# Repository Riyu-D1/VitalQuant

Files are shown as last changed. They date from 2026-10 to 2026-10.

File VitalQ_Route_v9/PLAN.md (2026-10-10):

# VitalQ v9 execution plan

## Source and protection

Start from the hand-edited v9 board dated 2026-10-09 10:19. Do not use the newer autosave. The B0_original backup preserves the starting board/project/schematic/local project. v8 is read-only; Python imports from it must use -B/PYTHONDONTWRITEBYTECODE. No parts or net assignments may change. All locked parts, connectors, electrodes, mounting holes, outline, skin-side sensor placement and rule areas remain unchanged. U19, or U18 only if needed, may move with a complete reconnection and logged before/after. Unlocked small passives may move no more than 1 mm, logged individually.

## Rules

Source checked: https://jlcpcb.com/capabilities/pcb-capabilities (2026-10-09).

- Exactly six copper layers, ENIG, 1 oz capability basis. No 8-layer conversion.
- Global and netclass track width/clearance remain 0.1016 mm; never below 0.09 mm.
- Presets: 0.25 mm diameter / 0.15 mm hole for BGA POFV; 0.40 / 0.20 mm ordinary vias.
- Minimum diameter 0.25 mm, drill 0.15 mm, annular ring 0.05 mm, matching the explicitly requested 0.25/0.15 geometry. Larger existing lawful vias need not all be replaced.
- Via hole-to-foreign-copper and drilled hole-to-hole edge separation: 0.20 mm, enforced by project minima and vitalq_v2.kicad_dru. Same-net attached tracks/annuli are necessarily connected to the hole and are not foreign-copper clearance checks. Hole-to-hole applies regardless of net.
- Copper-to-outline/slot clearance remains 0.30 mm.
- Through vias only. Blind, buried and micro vias disabled and prohibited by custom rule.
- All via-in-pad must be explicitly flagged filled/capped and listed for epoxy-filled, copper-capped POFV ordering. JLC advertises this process on 6-layer boards; confirm actual order options and any small-hole surcharge rather than assuming every service is free.
- Never add vias or inner copper in hv_inner areas; never modify rule areas, including J8. A geometrically blocked pad is not authorization to notch a keepout.

## Ordered work

1. Back up, establish rules/presets, save/refill baseline DRC. Also retain inherited-rule comparison.
2. Correct the five named 0.6/0.3 vias and move LED2_K off In1.Cu, preserving existing connections.
3. Local GND repairs; C59/U18 +3V3 stitches; sensor bridge and TMP117_ALERT; J12 MP; evaluate fully reconnected U19 relocation.
4. U7 exact 0.25/0.15 POFV escapes on In2/B, with a local MISO_AD detour only if required.
5. U6/U22 authorized local rip-up window and POFV, restoring all removed-net connections; In3 fallback only with connected power pours.
6. Remaining outer-layer HV-safe long runs.
7. Keepout, via spacing, dangling copper and pad-clearance cleanup without rule relaxation.
8. Final saved/refilled DRC, geometry/protected-placement/connectivity audit, renders and complete report.

## Attempts and acceptance

Review v9 PROGRESS.md and v8 PROGRESS.md/REPORT.md before each attempt. Keep v8 failed approaches in the ledger; the explicit v9 strategies are not permission to repeat exhausted v8 searches. At most three genuinely distinct v9 attempts per net; inherited exhaustion remains visible. No grid-resolution-only retries. Count routing batches with no accepted open reduction, including search-only failures. Two consecutive non-improving routing batches stop routing and send all remaining work to the report. Rule establishment is the baseline, not a routing attempt. Artifact correction counts as a routing batch if copper is changed.

Every batch gets a dated backup first and exactly one outcome line afterward in PROGRESS.md. Candidate projects retain the same PCB/project/rules basename. Never accept stale-fill DRC. Accept only candidates preserving all original connected pad groups and protected geometry, with no new real DRC defects; a capped keepout count must be audited geometrically. Rejected candidates remain archived, not deleted. Track every via, segment change/removal, nudge, attempt and blocked reason in JSON ledgers. Freerouting, if justified, is one named-BLOCKED-net-only run with fixed original copper and a 10-minute timeout; not a fallback that bypasses the mandatory stop.

DRC command: /Applications/KiCad/KiCad.app/Contents/MacOS/kicad-cli pcb drc --refill-zones --save-board --all-track-errors --schematic-parity --format json -o <report> vitalq_v2.kicad_pcb.

Reported real violations exclude only library and silk/text presentation findings; parity is separate. KiCad's per-code cap means native totals are lower bounds and cannot replace the uncapped geometry audit. No manufacturing-release claim while opens or real violations remain.

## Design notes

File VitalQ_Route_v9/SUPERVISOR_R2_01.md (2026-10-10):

# Supervisor instructions R2 #01 (answers to your 5 questions + next batches)

Streak/acceptance policy for R2 (replaces the generic rule):
- R2-1 (restack) is structural and does NOT count toward the stop streak. Streak = 0 now.
- A batch is ACCEPTED if, after refilled DRC, unconnected does not rise AND real violations do not rise vs the batch start; it counts as "improving" if unconnected falls OR real violations fall. Stop only after two consecutive non-improving batches, then print "R2 STOPPED" and wait (as before).
- Per-net attempt counters for C59.1, U18.8, ADS1292_PWDN, IR_GATE, AD5940_RESET are reset, because the geometry changes below (part moves) make them new problems.

Answers:
1. Streak: reset (see above).
2. YES: local rip-up and re-route of +3V3_ANA, TX_5V and MISO_FL (and any other foreign F.Cu/B.Cu segment hit by the moved U18 pads/EP) inside x 23.5–29.5, y 39.5–49.0 is authorised. Log every removed segment uuid. Keep the U18 dx = -0.31 mm nudge (needed for U22 C1/D1 via-in-pad).
3. YES: local rip-up of the blocking F.Cu/B.Cu segments around U19, C59 and U18.8 is authorised, including inside the HV area ON OUTER LAYERS ONLY (hv_ownlayer only forbids pours). Re-routes inside any hv_inner area must stay on F.Cu/B.Cu; In2/In3 re-routes only outside hv_inner. Log every removed segment.
4. NO: do not accept a via touching the hv_inner edge. Use the part moves below instead.
5. YES: run the U19.16/D30.2 GND island fix by itself as batch R2-3 right now (43 -> 42). Accept it.

Placement moves (supervisor-instructed; verified on a copy: courtyard-legal, inside board outline, and they move ALL signal pads out of every hv_inner area):
- U19: move dy = +1.00 mm, dx = 0 (17.0877,43.4355 -> 17.0877,44.4355), rotation unchanged. With this move 0 U19 net pads remain inside hv_inner. Re-attach all U19 pin tracks (shift/re-route stubs), then drop the vias for ADS1292_PWDN, IR_GATE, AD5940_RESET (and any other U19 inner-layer escapes) OUTSIDE hv_inner, i.e. below y 43.4 band edge where the pin now lies. Alternative legal positions if needed: (dx,dy) = (+0.25,+1.0), (+0.5,+1.0), (+0.75,+1.0), (+1.0,+1.0).
- C59: move (dx,dy) = (+0.25, -1.00) (15.6477,40.5098 -> 15.8977,39.5098), rotation unchanged. This puts C59.1 out of hv_inner and is courtyard-legal (1.03 mm; authorised exception to the 1 mm passive limit). Re-attach C59.2 and give C59.1 a 0.4/0.2 via to the +3V3 plane (now In4) outside hv_inner. Alternatives: (+0.5,-1.0), (+0.75,-1.0).
- Log both moves in change_ledger.json and REPORT.md.

Batch order now:
- R2-3: GND island U19.16/D30.2 alone (accept at 42).
- R2-4: U19 move + C59 move + re-attachment + ADS1292_PWDN / IR_GATE / AD5940_RESET / C59.1 escapes (treat as one batch; acceptance at batch end).
- R2-5: U18 nudge (-0.31) + authorised rip-up/re-route around U18 + U18.7/U18.8 +3V3 vias (pin8 now outside hv? check; if still inside, F.Cu stub out of hv_inner to its own via).
- Then continue with PROMPT_R2 R2-3.. steps (via-in-pad fan-out U22/U6/U7, U6/U22 bottom-ring rip-up, remaining routing), renumbered sequentially.
After every batch print the 3-line summary. I render each batch and will send more exact instructions.

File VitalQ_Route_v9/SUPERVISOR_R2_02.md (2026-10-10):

# Supervisor instructions R2 #02 (priorities + expanded authority from the user)

## Expanded authority (user, 17:45) — log every use in change_ledger.json + REPORT.md
- Board size: chest wearable. Stay at 50 x 75 mm if at all possible. Grow ONLY after placement moves and via-in-pad have been tried, and then only a few mm (hard cap 55 x 80 mm); no other shape change without a stated reason.
- You may move/rotate ANY unlocked part, and (within the size cap above) reshape the board outline, and change stackup/via tech (8 layers or HDI only if truly needed; note cost) — netlist/function identical, no parts added/removed.
- Locked parts (skin-side sensor cluster U6/U22/U11/U20/U16, HV corridor parts, connectors J*) MAY now be moved if they are the blocker, but: skin sensors stay on the skin side, stay together as a cluster and still face/contact the skin; HV keeps its isolation clearances (rule areas move WITH their HV parts, same shape and clearance, never shrink); connectors stay reachable at the board edge. Prefer moving unlocked parts first.
- Do not loosen any JLC rule. No commit/push. Delete no files.

## Priority order (do not sink more than one more attempt into U19 now)
1. U19: ONE more attempt with a minimal-disturbance method: "drag with tracks" instead of rip-up. Move U19 (dy +1.00, or rotate 180 deg + dy +1.00 if that puts pins 3/4/7 facing open space south of y 44), move every track endpoint that sits on a moved pad centre by the same transform, keep the rest of each track, then only fix the resulting local clearance hits. Place the escape vias for pins 3 (ADS1292_PWDN), 4 (AD5940_RESET), 7 (IR_GATE) south of the hv_inner band (y > 43.4 + 0.2 + via radius). If it still fails, park U19 (mark DEFERRED, not BLOCKED) and move on.
2. U7 via-in-pad batch (13 opens, biggest win, sites were clear in the survey): 0.25/0.15 POFV at ball centres B3 BIOZ_FP, B4 AIN4_LPF0, B5 BIOZ_SP, B6 DE0, B7 VZERO0, C7 VBIAS0, D2 BIOZ_FN, D7 VREF_2V5, E7 SPI_MOSI, F2/F3 +3V3_ANA, F5 AD5940_GPIO0, F7 CS_AD5940; escape on In3 ("Signal Layer 4", now empty) first, In2 second, B third; reroute the single B.Cu MISO_AD track that blocks the F row. Split into two batches if needed (B/C/D rows, then E/F rows).
3. U22 via-in-pad + U18 nudge (R2-5 from #01) — LED1_K D1, LED2_K C1, LED3_K B1, MAX86178_INT B2 at x 26.9/26.5; escape on In3.
4. U6 via-in-pad + bottom ring rip-up (PROMPT_R2 R2-3/R2-4), escapes on In3/In2.
5. Leftovers (+3V3 stitches, TMP117_ALERT, J12 MP, AFE_N_PAD, U18.7/8, C59.1, U19 deferred) — if a pin is boxed in, move the part (authority above) instead of retrying the same geometry.
6. Cleanup to DRC clean (items_not_allowed, hole_clearance 0.2, dangling, SOT-23 clearances) — 0 real violations except the 29 accepted parity items and library/silk/text presentation warnings.
7. Fab outputs into ./fab/: JLC Gerbers (all 6 copper + masks, paste, silk, Edge.Cuts) + Excellon drill (PTH/NPTH) zipped as fab/vitalq_v2_gerbers.zip; BOM (fab/vitalq_v2_BOM.csv, JLC columns Comment,Designator,Footprint,LCSC) and CPL (fab/vitalq_v2_CPL.csv, Designator,Mid X,Mid Y,Layer,Rotation) via kicad-cli; fab/FAB_NOTES.md: 6-layer S/G/S/S/P/S, ENIG, 1.6 mm, via-in-pad POFV (epoxy filled + capped) for the 0.25/0.15 vias, min via 0.15 hole, track/space 0.09/0.1016. Verify: re-open gerbers with kicad-cli gerber/drill check or a parse, count layers/files, CPL refs == BOM refs == board footprints.

Keep the 3-line summary after every batch. I am watching every 5-10 minutes and will send exact geometry when you report a block.

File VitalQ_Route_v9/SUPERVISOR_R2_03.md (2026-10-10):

# Supervisor instructions R2 #03 — KEEP the R2-6 candidate and repair it (do not discard)

R2-6 candidate (candidates/R2-6/vitalq_v2.kicad_pcb) is a real improvement: unconnected 42 -> 32, real 252 -> 245, hole_clearance 40 -> 26. Its 7 "new faults" are 6 track_dangling + 1 via_dangling WARNINGS plus 2 nets it broke (SWEAT_WE, MISO_AD). Make it the base of batch R2-7 (copy it over the working board after a dated backup) and repair on top of it. Acceptance for R2-7: unconnected < 32 + 0 and real <= 245 and no new dangling items.

I rendered the candidate (F/In2/In3/B around U7) and queried its copper. Exact fixes:

## 1. Dangling In3 stubs (delete the dangling segment only; the nets are connected elsewhere)
- CS_AD5940, Signal Layer 4: stub ending near (36.536,10.181) (vertical (36.586,9.55)->(36.586,10.28) leftover).
- VBIAS0, Signal Layer 4: (36.486,11.431), 0.65 mm stub west of C7 via (36.586,11.481).
- BIOZ_FP, Signal Layer 4: (38.136,11.981), 0.7 mm stub south of B3 via (38.186,11.881).
- BIOZ_SP, Signal Layer 4: (37.436,11.981), 0.7 mm stub south of B5 via (37.386,11.881).
- BIOZ_FN, Signal Layer 4: (38.686,11.031), the dangling part of the T east of D2 via (38.586,11.081) (keep the part that leads to the long vertical at x~38.99 if that is the real route).
- uuids from your decision.json: 35a19dc6, 3854008f, 47792255, adf22370, eec6d8c7 (check each is one of the above before deleting). Pre-existing GND dangling (28.936,37.201) / via (6.829,62.871) / AFE4900_RESETZ zero-length (10.75,61.05) are old — leave them for cleanup.

## 2. SWEAT_WE (U7 C5 @ 37.386,11.481) — currently boxed in by via-in-pads
Neighbouring via-in-pads: D5 GND (37.386,11.081), C4 GND (37.786,11.481), B5 BIOZ_SP (37.386,11.881); the only free neighbour pocket C6/D6 (36.986,11.481 / 11.081) is closed by C7 VBIAS0, D7 VREF_2V5, E6 GND, B6 DE0 vias. At 0.4 pitch no track can pass between two via-in-pads (JLC 0.2 hole-to-track), so a via must go.
- Delete the GND via-in-pad at D5 (37.386,11.081) (GND is redundant here: E6 and C4 GND vias stay). Tie D5 pad to E5 pad (37.386,10.681, GND) with a straight 0.1016 F.Cu track; make sure E5 reaches E6 (36.986,10.681) or E4/E3 GND on F (add the 0.4 mm pad-to-pad F track E5->E6 if not already there).
- Inner-layer channel now open (all of these balls have NO via): D5 (37.386,11.081) -> D4 (37.786,11.081) -> D3 (38.186,11.081) -> C3 (38.186,11.481) -> C2 (38.586,11.481) -> B2 (38.586,11.881) -> A2 (38.586,12.281) -> south out of the array; and the north branch D4 -> E4 (37.786,10.681) -> F4 (37.786,10.281) -> G4 (37.786,9.881) -> north out. Track centres on ball centres are 0.40 from every neighbouring via (legal: needs >= 0.32 for a 0.09-0.1016 track).
- Route SWEAT_WE from the C5 via on In2 (or In3) through one of those channels to the rest of the net. The net continues on B.Cu from via (36.95,14.55) down to (36.95,16.0) -> (37.15,16.35) -> (38.3,17.5) -> (38.65,17.75..18.9) ...; you may join that B track anywhere (e.g. drop a new 0.4/0.2 via on the In2/In3 path and land on the B track near (37.15,16.35)-(38.3,17.5)), and then delete the orphaned old In2 piece (36.85,12.70)->(36.8,14.4)->via(36.95,14.55) and that via if they become dangling.

## 3. MISO_AD (U7 E8 @ 36.186,10.681 -> R91.1 @ 44.313,11.855)
- The old B.Cu run along y~10.24 was ripped because it sat on the F-row via-in-pads (y 10.281). Left: F stub E8 -> via (34.465,10.447) with B stub to (34.607,10.305); and R91 side F track -> via (43.224,11.147) with B stub to (43.082,11.006).
- Via-free inner channels through U7: row G (y = 9.881, all G balls have no via) and column 8 (x = 36.186, no vias). On B there are now only via barrels under U7 plus the CS_AD5940 / SPI_MOSI escape diagonals west of U7 (to (36.586,10.281) and (36.586,10.681)).
- Preferred: B.Cu from via (34.465,10.447) north/around the CS_AD5940 diagonal to y ~9.3, east along y ~9.3 (north of row G, clear of the G-row pads which are F-only), then down the east side to via (43.224,11.147). If B is blocked west of U7, use In2 along row G (y 9.881) between the F-row vias (0.40 clearance) — but first check In2's diagonal near (35.0,10.95)->(37.64,8.5); use In3 if that one is in the way. Reuse the two existing MISO_AD vias; delete the two 0.2 mm B stubs if not used.

## After R2-7
Continue SUPERVISOR_R2_02 priorities: U22 via-in-pad + U18 nudge next, then U6. Print the 3-line summary after each batch.

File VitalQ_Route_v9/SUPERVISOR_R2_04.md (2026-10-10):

# Supervisor instructions R2 #04 — U6 (AFE4900, B side, 0.4 mm WLP) escape plan
(from renders of candidates/R2-7 + copper query; use after the U22 batch)

## Grid (B side balls; x by column, y by row)
cols: 1=26.5, 2=26.1, 3=25.7, 4=25.3, 5=24.9 ; rows: A=49.8, B=50.2, C=50.6, D=51.0, E=51.4, F=51.8
Opens on U6: A1 AFE_INM, A2 PD_INP, A3 PD_INM, B2 PD2_INP, B3 PD2_INM, C4 +3V3_ANA, D2 AFE_BG, D4 TX1, E2 MISO_AFE, E3 CS_AFE4900, E4 TX3, E5 TX2, F2 SPI_MOSI, F3 SPI_SCK.
Existing GND via-in-pads (keep): B4 (25.3,50.2), D1 (26.5,51.0), D5 (24.9,51.0).

## Layer situation under U6 (rendered)
- In3 (Signal Layer 4): EMPTY under and around U6/U22. Use it first.
- F.Cu above U6 (x 24.4–27.0, y 49.4–51.9): EMPTY except the GND via tops. Usable as an escape layer (U6 is on B). TX_5V F diagonal (27.13,49.27)->(29.03,51.17) is the first obstacle east.
- In2: two foreign tracks run THROUGH the array and must be ripped inside x 24.0–27.0, y 49.0–52.2 (authorised, log uuids) and re-routed afterwards outside the array:
  - ESP_TX: (24.84,49.93)->(24.84,50.25)->(25.26,50.70)->(25.26,51.15)->(24.84,51.45) (sits on C4/D4/E4 sites).
  - AFE_INP: (26.97,49.71 via)->(26.95,50.0)->(26.95,51.2)->(26.36,51.4)->(26.36,54.6) (sits on the E1/F1 east channel and between col1/col2). Re-route AFE_INP from its B1 pad stub/via (26.97,49.71) on In2 EAST of x 27.3 or on F.
- B.Cu: ring of TX4 / TX_5V / +1V8 / +3V3_ANA / AFE_CLK / ADC_RDY / RESETZ / AFE_INP hugging the array — leave it; all new escapes go through via-in-pad to F/In2/In3.

## Via-in-pad set (0.25/0.15 POFV at ball centre)
A1, A2, A3, B2, B3, C4, D2, D4, E2, E3, E4, E5, F2, F3 (+ existing B4, D1, D5).
Free (no-via) cells that form the channels: A4, A5, B1, B5, C1, C2, C3, C5, D3, E1, F1, F4, F5.
Rule reminder: a track on a ball-centre line is 0.40 from the neighbouring via centres (legal, >= 0.32 needed); a track can NOT pass between two adjacent vias or diagonally past one (0.28).

## Escape topology (forced by the grid)
- Row A (A1, A2, A3): boundary — escape NORTH (y < 49.6) on any layer.
- E5, F2, F3: boundary — escape west (E5) / south (F2, F3).
- E4 TX3: E4 -> F4 (25.3,51.8) -> south.
- C4 +3V3_ANA: C4 -> C5 (24.9,50.6) -> west.
- E2 MISO_AFE: E2 -> E1 (26.5,51.4) -> east.
- B2 PD2_INP: B2 -> B1 (26.5,50.2) -> east.
- B3 PD2_INM, D2 AFE_BG, D4 TX1, E3 CS_AFE4900 all MUST use the C2 -> C1 -> east exit (B3 via C3; D4 and E3 via D3 -> C3; D2 directly via C2). That is 4 nets through one cell sequence, so they need 4 different layers: assign D2 AFE_BG = F.Cu (target C15.1 @ 28.776,50.042 is on F; cross the TX_5V F diagonal by dropping to In3 for 0.5 mm or go around its north end at (27.13,49.27)), B3 PD2_INM = In3, D4 TX1 = In2 (after the ESP_TX/AFE_INP rip), E3 CS_AFE4900 = In4 (Power Layer 5: a short local track is allowed; the +3V3 pour refills around it and must stay connected — check) OR move CS_AFE4900 onto F and AFE_BG onto In4. If you find a 3-layer solution, better.
- After exiting east (x >= 26.9), PD2_INP / PD2_INM / TX1 must loop to U16 (B side, locked, 13.4,56.0; pads PD_INP 10.4,57.25 / PD_INM 11.6,57.25 / PD2_INP 12.8,57.25 / TX1 16.4,57.25 / TX3 15.2,54.75 / PD2_INM 12.8,54.75 / TX2 10.4,54.75): go south on In3 east of the array (x ~27.0–27.3, In3 is empty there), then west along y ~52.5–53.5 on In3 under U6's south side, then to U16 with vias next to its pads (outside any hv_inner area). PD_INP / PD_INM (A2/A3) go north 0.3–0.8 mm, then west on In3 along y ~49.0/49.4, then south-west to U16.
- A1 AFE_INM joins its existing F.Cu track (8.39 mm piece) — via A1 to F, then F.
- MISO_AFE (E2) target R90.1 (44.897,49.062, F) — east on In3/In2, via near R90.
- SPI_MOSI / SPI_SCK (F2/F3): south via F row, then to the SPI bus (SPI_SCK must also reach U22 A2 @26.5,46.95).

Do this as one or two batches (row-A/E5/F-row/E4/C4/E2/B2 first; then the 4-layer C-channel group). Print the 3-line summary after each.

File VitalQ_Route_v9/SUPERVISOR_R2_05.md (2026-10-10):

# Supervisor instructions R2 #05 — decision on the J8 no-via area over U6

J8 = Tag-Connect TC2030-IDC-NL on F at (26.45,53.2), locked. Its footprint no-via/no-fill F rule area covers x 25.18–27.72, y 50.06–51.34, i.e. U6 balls B1–B4, C1–C4, D1–D4 (and E-row annuli touch it). v8 already granted two POFV exceptions there (D1/B4 GND) using per-via notches (see ../VitalQ_Route_v8 j8_pofv_policy.json, scripts/j8_pofv.py).

DECISION (user granted structural authority): extend the SAME v8 mechanism to every U6 via-in-pad you need under J8.
- Allowed: 0.25/0.15 via-in-pad exactly at U6 ball centres, POFV (epoxy-filled + copper-capped, planar), each with its own notch in the J8 F no-via area of exactly the via annulus + 0.002 mm, recorded in j8_pofv_policy / j8_permitted_vias (new R2 file is fine). Rationale: the area exists so the Tag-Connect head sits on a flat surface; a POFV cap is planar and soldermask-covered.
- Not allowed: any non-POFV via, any between-ball via, any track/via change elsewhere in the J8 area, any change to hv_* rule areas.
- Flag all of them in REPORT.md and fab/FAB_NOTES.md as "POFV mandatory (planar, under Tag-Connect J8 landing)".
- Fallback only if this proves impossible: rotate J8 180 deg and shift dx +0.50 mm (-> 26.95,53.2): verified courtyard-legal, its keepout then lands at x 25.68–28.22, y 55.06–56.34 covering 0 U6 balls and 0 existing vias; but it needs re-attachment of all 6 J8 nets and relocation of the GND via (25.798,52.987), +3V3 via (24.589,54.532) and ESP_EN via (29.6,53.283) which would collide with the moved pads/NPTH holes. Use only if the notch approach fails.

So: proceed with the full U6 plan of SUPERVISOR_R2_04 including the J8-covered balls (B2, B3, C4, D2, D4, E2, E3, E4) using notched POFV exceptions.

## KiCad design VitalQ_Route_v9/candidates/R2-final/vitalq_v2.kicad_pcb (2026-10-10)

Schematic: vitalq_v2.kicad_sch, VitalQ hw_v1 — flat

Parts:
C1, C47: 4.7u; C_0603_1608Metric
C2, C9, C20: 4.7u; C_0402_1005Metric
C3, C4, C6, C11, C14, C16, C19, C26, C32, C33, C42, C43, C64, C66, C80, C82, C83, C84: 1u; C_0402_1005Metric
C7, C45: 22u; C_0603_1608Metric
C8, C13, C15, C18, C24, C25, C27, C28, C29, C36, C37, C38, C39, C40, C41, C50, C51, C56, C57, C58, C59, C60, C61, C62, C63, C76, C77, C78, C79, C81: 100n; C_0402_1005Metric
C10: 1u; C_0603_1608Metric
C21, C22, C23, C55, C68, C69, C70: 470n; C_0402_1005Metric
C30: 10u; C_0402_1005Metric
C34: 47n; C_0402_1005Metric
C35: 4.7n; C_0402_1005Metric
C44: 10u; C_0603_1608Metric
C46: 2.2u; C_0402_1005Metric
C48, C49, C52, C53: 2.2n; C_0402_1005Metric
C54, C67: 15n; C_0402_1005Metric
C65: 1.5n; C_0402_1005Metric
C85: 47u; C_0603_1608Metric
C86, C88, C90, C91: 100n; C_0402_1005Metric; LCSC C1525
C87: 10u; C_0402_1005Metric; LCSC C15525
C89: 10u; C_0603_1608Metric; LCSC C19702
D1, D2, D3, D4, D5, D6, D7, D8, D9, D21, D22, D23, D24, D26, D27, D28, D29, D30: TPD1E10B06; TPD1E10B06_DPY
D10: NF2W757G-F1; NF2W757G
D11: SFH4053; LED_0402_1005Metric
D12: SFH 4735 730nm; LED_0402_1005Metric
D25: KT-0603G; LED_0603_1608Metric
FID1, FID2, FID3, FID4, FID5, FID6: FID; Fiducial_1mm
H1, H2: M2; MountingHole_2.2mm_M2
J1: USB-C; USB_C_Receptacle_HRO_TYPE-C-31-M-12
J2: LiPo pads; Pads_LiPo
J3: FSR pads; Pads_FSR
J5: ECG pads; Pads_ECG
J6: EDA pads; Pads_EDA
J7: Chest bioZ; Pads_BIOZ
J8: TC2030; Tag-Connect_TC2030-IDC-NL_2x03_P1.27mm_Vertical
J9: I2C tail pads; Pads_1x04
J10: Optical tail pads; Pads_1x06
J11: Sweat site; Pads_1x03
J12: FH12-14S; Hirose_FH12-14S-0.5SH_1x14-1MP_P0.50mm_Horizontal; not fitted
J13: MX ECG pads; Pads_1x02; not fitted
L1: 0.47u; L_DFE201612E
L2: 1.0u; L_DFE201612E
Q1, Q2, Q4: CSD13380F3T; Texas_PicoStar_DFN-3_0.69x0.60mm
Q3: BC847BS,115; SOT-363_SC-70-6
R1, R2: 5.1k; R_0402_1005Metric
R3: 1.5k; R_0402_1005Metric
R5, R6, R7, R8, R9, R11, R14, R49, R52, R53, R60, R65, R67, R68, R69, R70, R71, R74, R98, R100, R101, R112, R113, R115, R116, R117: 10k; R_0402_1005Metric
R10, R13, R39, R40, R41, R42, R62, R72, R73, R84, R85, R86, R87, R88: 1k; R_0402_1005Metric
R12: 10; R_0402_1005Metric
R15, R16, R17: 1M; R_0402_1005Metric
R18, R51: 200k; R_0402_1005Metric
R19, R20, R21, R22: 4.7k; R_0402_1005Metric
R23: 560k; R_0402_1005Metric
R24, R25, R44, R46, R48, R50, R59, R99, R110: 100k; R_0402_1005Metric
R26, R27, R28, R29: 10M; R_0402_1005Metric
R30, R31: 40.2k; R_0402_1005Metric
R32, R33, R34, R35, R36, R76, R77, R78, R79, R80, R81, R82, R83: 51k; R_2512_6332Metric
R43, R45: 5.11M; R_0402_1005Metric
R47, R109: 100; R_0402_1005Metric
R61: 10k; R_0402_1005Metric; not fitted
R63: 22.1k; R_0402_1005Metric
R64: 47.5k; R_0402_1005Metric
R66: 301k; R_0402_1005Metric
R75: 27.0k; R_0402_1005Metric
R89, R90, R91, R92, R95, R96, R97, R102, R103, R106, R114: 0; R_0402_1005Metric
R93, R94: 0; R_0603_1608Metric
R104, R105: 0; R_0402_1005Metric; not fitted
R107, R108: 100k; R_0402_1005Metric; not fitted
R118, R119, R120, R121, R122: 0; R_2512_6332Metric
SW1, SW2: TS-1088; SW_SPST_TS-1088-xR020
TP1: VBUS; TestPoint_Pad_D1.0mm
TP2: VBAT; TestPoint_Pad_D1.0mm
TP3: +3V3; TestPoint_Pad_D1.0mm
TP4: +1V8; TestPoint_Pad_D1.0mm
TP5: TX_5V; TestPoint_Pad_D1.0mm
TP6: VDD_CP2102; TestPoint_Pad_D1.0mm
TP7, TP8: GND; TestPoint_Pad_D1.0mm
TP9: ESP_EN; TestPoint_Pad_D1.0mm
TP10: ESP_IO0; TestPoint_Pad_D1.0mm
TP11: ESP_TX; TestPoint_Pad_D1.0mm
TP12: ESP_RX; TestPoint_Pad_D1.0mm
TP13: I2C_SDA; TestPoint_Pad_D1.0mm
TP14: I2C_SCL; TestPoint_Pad_D1.0mm
TP15: I2C_SDA_1V8; TestPoint_Pad_D1.0mm
TP16: I2C_SCL_1V8; TestPoint_Pad_D1.0mm
TP17: SPI_SCK; TestPoint_Pad_D1.0mm
TP18: SPI_MOSI; TestPoint_Pad_D1.0mm
TP19: SPI_MISO; TestPoint_Pad_D1.0mm
TP20: CS_ADS1292; TestPoint_Pad_D1.0mm
TP21: CS_AFE4900; TestPoint_Pad_D1.0mm
TP22: CS_AD5940; TestPoint_Pad_D1.0mm
TP23: CS_FLASH; TestPoint_Pad_D1.0mm
TP24: ADS1292_DRDY; TestPoint_Pad_D1.0mm
TP25: AFE4900_ADC_RDY; TestPoint_Pad_D1.0mm
TP26: EXP_INT; TestPoint_Pad_D1.0mm
TP27: CHG_STAT; TestPoint_Pad_D1.0mm
TP28: RTC_INT; TestPoint_Pad_D1.0mm
U1: ESP32-S3-MINI-1-N4R2; ESP32_S3_MINI_1
U2: BQ25170DSGR; Texas_DSG0008A_WSON-8-1EP_2x2mm_P0.5mm_EP0.9x1.6mm
U3: TPS63802DLAR; WSON-10-1EP_2x3mm_P0.5mm_EP0.84x2.4mm
U4: TPS7A2018PDBVR; SOT-23-5
U5: CP2102N-A02-GQFN28R; QFN-28-1EP_5x5mm_P0.5mm_EP3.35x3.35mm
U6: AFE4900YZR; BGA30N40P5X6_260X210X50
U7: AD5940BCBZ-RL7; BGA56C40P8X7_416X356X55
U8: ADS1292RIRSMT; QFN40P400X400X100-33N-D
U9: PCA9306DCUR; VSSOP-8_2.3x2mm_P0.5mm
U10: AS7341-DLGM; AS7341DLGT
U11, U20: TMP117AIDRVR; TMP117_DRV_NOPASTE
U12: MLX90632SLD-DCB-100-SP; MLX90632SLDDCB100SP
U13: BME280; Bosch_LGA-8_2.5x2.5mm_P0.65mm_ClockwisePinNumbering
U14: LSM6DSV80XTR; QFN_LSM6DSV80XTR_STM
U15: TPS61240YFFR; TPS61240_YFF
U16: SFH 7072; SFH7072
U17: MAX17048G+T10; TDFN-8-1EP_2x2mm_P0.5mm_EP0.8x1.2mm
U18: W25Q512JVEIQ; W25Q512_WSON8
U19: TCA6408ARSVR; TCA6408A_RSV
U21: USBLC6-2SC6; SOT-23-6
U22: MAX86141ENP+; MAX86141_WLP20; LCSC C5328762
U23: SHT45-AD1B; SHT45_DFN4
U24: RV-3028-C7; RV3028C7
U25: IM69D130
U26: SN74AXC2T245RSWR; Texas_RSW0010A_UQFN-10_1.4x1.8mm_P0.4mm; LCSC C1882550

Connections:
+1V8: C36.1, C86.1, C87.1, C88.1, C90.1, R21.1, R22.1, R66.1, R97.2, TP4.1, U9.2 (VREF1), U10.1 (VDD), U22.C2 (VDD_DIG), U22.D2 (VDD_ANA), U26.7 (VCCA), U26.10 (DIR1)
+1V8_LDO: C6.1, R97.1, U4.5 (OUT)
+3V3: C4.1, C37.1, C38.1, C39.1, C40.1, C41.1, C45.1, C59.1, C60.1, C61.1, C76.1, C77.1, C78.1, C81.1, C84.1, C91.1, D10.1 (A), J3.1, J8.1, J9.1, J12.1, R5.1, R6.1, R7.1, R18.1, R19.1, R20.1, R23.1, R47.1, R49.1, R52.1, R53.1, R60.1, R65.1, R74.1, R94.1, R95.1, R98.1, R99.1, R109.1, R112.1, R113.1, R117.1, TP3.1, U3.6 (VOUT), U4.1 (IN), U4.3 (EN), U11.5 (V+), U12.2 (VDD), U13.2 (CSB), U13.6 (VDDIO), U13.8 (VDD), U14.5, U14.8, U14.12, U18.3 (~WP/IO_{2}), U18.7 (~HOLD/~RESET/IO_{3}), U18.8 (VCC), U19.14 (V_{CCP}), U19.15 (V_{CCI}), U20.4 (ADD0), U20.5 (V+), U23.3 (VDD), U24.7 (VDD), U25.2 (VDD), U26.6 (VCCB)
+3V3_ANA: C11.1, C13.1, C16.1, C18.1, C28.1, C29.1, C43.1, C79.1, C80.1, R12.1, R15.1, R26.1, R28.1, R95.2, R116.1, U6.A4 (I2C_SPI_SEL), U6.C1 (RX_SUP), U6.C4 (IO_SUP), U7.A4 (AVDD_1), U7.F2 (AVDD_2), U7.F3 (DVDD), U8.12 (AVDD), U8.14 (CLKSEL), U8.23 (DVDD)
+3V3_ESP: C7.1, C8.1, R94.2, U1.3 (3V3)
AD5940_GPIO0: U1.18 (IO14), U7.F5 (GPIO0)
AD5940_RESET: R11.1, U7.F1 (~RESET), U19.4 (P2)
ADS1292_DRDY: R99.2, TP24.1, U1.6 (IO2), U8.22 (~DRDY)
ADS1292_PWDN: R14.1, U8.15 (~PWDN/~RESET), U19.3 (P1)
ADS_GPIO1: R100.1, U8.26 (GPIO1/RCLK1)
ADS_GPIO2: R101.1, U8.25 (GPIO2/RCLK2)
AFE4900_ADC_RDY: TP25.1, U1.25 (IO21), U6.F4 (ADC_RDY)
AFE4900_RESETZ: R9.1, U6.E1 (RESETZ), U19.2 (P0)
AFE_BG: C15.1, U6.D2 (BG)
AFE_CLK: R10.1, U6.F1 (CLK)
AFE_INM: C57.2, R45.2, U6.A1 (INM_ECG)
AFE_INP: C56.2, R43.2, U6.B1 (INP_ECG)
AFE_N_AC: D5.1, R36.2, R46.1
AFE_N_PAD: J5.5, R36.1
AFE_N_SER: C57.1, R46.2
AFE_P_AC: D4.1, R35.2, R44.1
AFE_P_PAD: J5.4, R35.1
AFE_P_SER: C56.1, R44.2
AIN4_LPF0: C26.1, U7.B4 (AIN4/LPF0)
AVDD_REG: C42.1, U7.D8 (AVDD_REG)
BIOZ_FN: C68.2, U7.D2 (AIN0)
BIOZ_FN_PAD: J7.2, R81.1
BIOZ_FP: R84.2, U7.B3 (AIN1)
BIOZ_FP_PAD: J7.1, R80.1
BIOZ_SN: C70.2, U7.A3 (AIN2)
BIOZ_SN_PAD: J7.4, R83.1
BIOZ_SP: C69.2, U7.B5 (AIN3/BUF_VREF1V8)
BIOZ_SP_PAD: J7.3, R82.1
CE0: R39.2, U7.A7 (CE0)
CE_ISO: C54.2, D6.1, R39.1
CE_SURGE: C54.1, R76.2
CHG_DIS: Q2.1 (G), R59.1, U19.10 (P7)
CHG_ISET: R3.1, U2.2 (ISET)
CHG_PG: R60.2, U1.11 (IO7), U2.6 (~PG)
CHG_STAT: R49.2, TP27.1, U2.5 (STAT), U19.8 (P5)
CHG_VSET: R75.1, U2.7 (VSET)
CP_DTR: Q3.4 (E2), R70.1, U5.28 (~DTR)
CP_RST: R62.2, U5.9 (~RST)
CP_RTS: Q3.1 (E1), R71.1, U5.24 (~RTS)
CP_RX: R72.2, U5.25 (RXD)
CP_TX: R73.1, U5.26 (TXD)
CP_VBUS: R63.2, R64.1, U5.8 (VBUS)
CS_AD5940: R7.2, TP22.1, U1.19 (IO15), U7.F7 (~CS)
CS_ADS1292: R98.2, TP20.1, U1.14 (IO10), U8.18 (~CS)
CS_AFE4900: R116.2, TP21.1, U1.22 (IO18), U6.E3 (SEN)
CS_FLASH: R52.2, TP23.1, U1.20 (IO16), U18.1 (~CS)
CS_MAX86178: R117.2, U1.34 (IO38), U22.A5 (CSB), U26.2 (OE)
DE0: R42.2, U7.B6 (DE0)
DE_SURGE: D9.1, R42.1, R79.2
DVDD_REG: C23.1, U7.G3 (DVDD_REG_1V8)
ECG1_PAD: J5.1, R32.1
ECG2_PAD: J5.2, R33.1
ECG_N: C51.1, C53.1, D2.1, R31.2, R33.2, U8.5 (IN2N)
ECG_P: C50.1, C52.1, D1.1, R30.2, R32.2, U8.6 (IN2P)
EDA_CE_PAD: J6.1, R76.1
EDA_DE_PAD: J6.4, R79.1
EDA_RE_PAD: J6.2, R78.1
EDA_SE_PAD: J6.3, R77.1
ESP_EN: C64.1, J8.5, Q3.6 (C1), R5.2, SW1.1, TP9.1, U1.45 (EN), U19.1 (~RESET)
ESP_IO0: J8.6, Q3.3 (C2), R6.2, SW2.1, TP10.1, U1.4 (IO0)
ESP_RX: J8.4, R73.2, TP12.1, U1.40 (RXD0)
ESP_TX: J8.3, R72.1, TP11.1, U1.39 (TXD0)
EXP_INT: R53.2, TP26.1, U1.7 (IO3), U19.11 (~INT)
FB_3V3: R23.2, R24.1, U3.4 (FB)
FN_ISO: C68.1, D22.1, R85.2
FN_SURGE: R81.2, R85.1
FP_ISO: C67.2, D21.1, R84.1
FP_SURGE: C67.1, R80.2
FSR_ADC: J3.2, R8.1, U1.5 (IO1)
GAUGE_ALRT: R74.2, U1.10 (IO6), U17.5 (ALRT)
GND: C1.2, C2.2, C3.2, C4.2, C6.2, C7.2, C8.2, C9.2, C10.2, C11.2, C13.2, C14.2, C15.2, C16.2, C18.2, C19.2, C20.2, C21.2, C22.2, C23.2, C24.2, C25.2, C26.2, C28.2, C29.2, C30.2, C32.2, C33.2, C36.2, C37.2, C38.2, C39.2, C40.2, C41.2, C42.2, C43.2, C44.2, C45.2, C46.2, C47.2, C48.2, C49.2, C52.2, C53.2, C58.2, C59.2, C60.2, C61.2, C62.2, C63.2, C64.2, C66.2, C76.2, C77.2, C78.2, C79.2, C80.2, C81.2, C82.2, C83.2, C84.2, C85.2, C86.2, C87.2, C88.2, C89.2, C90.2, C91.2, D1.2, D2.2, D3.2, D4.2, D5.2, D6.2, D7.2, D8.2, D9.2, D21.2, D22.2, D23.2, D24.2, D25.2 (K), D26.2, D27.2, D28.2, D29.2, D30.2, J1.A1 (GND), J1.A12 (GND), J1.B1 (GND), J1.B12 (GND), J1.SH (SHIELD), J2.2, J8.2, J9.4, J12.4, Q1.2 (S), Q2.2 (S), Q4.2 (S), R1.2, R2.2, R3.2, R8.2, R9.2, R10.2, R11.2, R14.2, R16.2, R24.2, R25.2, R27.2, R29.2, R48.2, R51.2, R59.2, R61.2, R64.2, R66.2, R75.2, R100.2, R101.2, R108.2, R110.2, R115.2, SW1.2, SW2.2, TP7.1, TP8.1, U1.1 (GND), U1.2 (GND), U1.42 (GND), U1.43 (GND), U1.46 (GND), U1.47 (GND), U1.48 (GND), U1.49 (GND), U1.50 (GND), U1.51 (GND), U1.52 (GND), U1.53 (GND), U1.54 (GND), U1.55 (GND), U1.56 (GND), U1.57 (GND), U1.58 (GND), U1.59 (GND), U1.60 (GND), U1.61 (GND), U1.62 (GND), U1.63 (GND), U1.64 (GND), U1.65 (GND), U2.4 (GND), U2.9 (EP), U3.2 (MODE), U3.3 (AGND), U3.8 (GND), U3.11 (EP), U4.2 (GND), U5.3 (GND), U5.29 (GND), U6.B4 (CONTROL1), U6.D1 (RX_GND), U6.D5 (TX_GND), U7.C4 (AGND_1), U7.D5 (AGND_REF), U7.E3 (AGND_2), U7.E4 (DGND_1), U7.E5 (DGND_2), U7.E6 (DGND_3), U8.10 (VREFN), U8.13 (AVSS), U8.16 (START), U8.17 (CLK), U8.24 (DGND), U8.33 (EP), U9.1 (GND), U10.3 (GND), U10.5 (PGND), U11.2 (GND_1), U11.4 (ADD0), U11.7 (GND_2), U12.3 (GND), U12.5 (ADDR), U12.6 (EP), U13.1 (GND), U13.5 (SDO), U13.7 (GND), U14.1, U14.2, U14.3, U14.6, U14.7, U15.A2 (GND), U17.1 (CTG), U17.4 (GND), U17.6 (QSTRT), U17.9 (EP), U18.4 (GND), U18.9 (EP), U19.6 (GND), U19.16 (ADDR), U20.2 (GND_1), U20.7 (GND_2), U21.2 (GND), U22.C3 (GND_DIG), U22.C4 (GND_ANA), U22.D3 (PGND), U23.4 (VSS), U24.5 (VSS), U24.8 (EVI), U25.4 (SELECT), U25.5 (GND), U26.1 (DIR2), U26.3 (GND), U26.4 (B2)
I2C_SCL: J9.3, J12.3, R20.2, TP14.1, U1.13 (IO9), U9.6 (SCL2), U11.1 (SCL), U13.4 (SCK), U14.13, U17.7 (SCL), U19.12 (SCL), U20.1 (SCL), U23.2 (SCL), U24.3 (SCL)
I2C_SCL_1V8: R22.2, TP16.1, U9.3 (SCL1), U10.2 (SCL), U12.4 (SCL)
I2C_SDA: J9.2, J12.2, R19.2, TP13.1, U1.12 (IO8), U9.5 (SDA2), U11.6 (SDA), U13.3 (SDI), U14.14, U17.8 (SDA), U19.13 (SDA), U20.6 (SDA), U23.1 (SDA), U24.4 (SDA)
I2C_SDA_1V8: R21.2, TP15.1, U9.4 (SDA1), U10.8 (SDA), U12.1 (SDA)
IN1N: C49.1, R28.2, R29.1, R68.2, U8.3 (IN1N)
IN1N_AC: C51.2, R68.1
IN1P: C48.1, R26.2, R27.1, R67.2, U8.4 (IN1P)
IN1P_AC: C50.2, R67.1
IOVDD: C19.1, R12.2, U7.G2 (IOVDD)
IR_AN: D11.1 (A), R47.2
IR_GATE: Q1.1 (G), R48.1, U19.7 (P4)
IR_K: D11.2 (K), Q1.3 (D)
J11_CE: J11.3, R122.1
J11_RE: J11.2, R121.1
J11_WE: J11.1, R120.1
J13_INM: J13.2, R119.1
J13_INP: J13.1, R118.1
LDR: D10.2 (K), U10.4 (LDR)
LED1_K: J10.1, J12.5, U22.D1 (LED1_DRV)
LED2_K: J10.2, J12.6, U22.C1 (LED2_DRV)
LED3_K: J10.3, J12.7, U22.B1 (LED3_DRV)
LED_A: D25.1 (A), R88.2
LED_AN: J10.4, J12.8, R114.2
LSM6_INT1: U1.8 (IO4), U14.4
MAX86178_INT: R113.2, U1.35 (IO39), U22.B2 (INT)
MIC_CLK: U1.36 (IO40), U25.3 (CLOCK)
MIC_DAT: U1.37 (IO41), U25.1 (DATA)
MISO_AD: R91.1, U7.E8 (MISO)
MISO_ADS: R89.1, U8.21 (DOUT)
MISO_AFE: R90.1, U6.E2 (SDOUT)
MISO_FL: R92.1, U18.2 (DO/IO_{1})
MISO_MX: R106.1, U26.5 (B1)
MX_ECG_INM: D30.1, R119.2
MX_ECG_INP: D29.1, R118.2
MX_SDO_1V8: U22.A3 (SDO), U26.8 (A1)
MX_VREF: C83.1, U22.B5 (VREF)
NIR730_GATE: Q4.1 (G), R110.1, U7.E1 (GPIO2)
NIR_AN: D12.1 (A), R109.2
NIR_K: D12.2 (K), Q4.3 (D)
PD2_INM: U6.B3 (INM2), U16.10 (PD2_A)
PD2_INP: U6.B2 (INP2), U16.3 (PD2_C)
PD_A: J10.6, J12.10, U22.C5 (PD_GND)
PD_INM: U6.A3 (INM), U16.2 (PD1_A)
PD_INP: U6.A2 (INP), U16.1 (PD1_C)
PD_K: J10.5, J12.9, U22.D5 (PD1_IN)
PGA1N: C34.1, U8.1 (PGA1N)
PGA1P: C34.2, U8.2 (PGA1P)
PGA2N: C35.1, U8.7 (PGA2N)
PGA2P: C35.2, U8.8 (PGA2P)
Q3_B1: Q3.2 (B1), R70.2
Q3_B2: Q3.5 (B2), R71.2
RC0_0: C27.1, U7.C8 (RC0_0)
RC0_1: C27.2, U7.B8 (RC0_1)
RCAL0: R13.1, U7.C1 (RCAL0)
RCAL1: R13.2, U7.B1 (RCAL1)
RE0: R41.2, U7.A8 (RE0)
RESP_MODN: R31.1, U8.32 (RESP_MODN/IN3N)
RESP_MODP: R30.1, U8.31 (RESP_MODP/IN3P)
RE_SURGE: D8.1, R41.1, R78.2
RLDINV: C65.2, R17.2, U8.28 (RLDINV)
RLDOUT: C65.1, R17.1, R43.1, R45.1, R69.2, U8.30 (RLDOUT)
RLDREF: C66.1, R15.2, R16.1, U8.29 (RLDIN/RLDREF)
RLD_CLAMP: D3.1, R34.2, R69.1
RLD_PAD: J5.3, R34.1
RTC_INT: R112.2, TP28.1, U24.2 (INT)
RTC_VBK: R115.1, U24.6 (VBACKUP)
SE0: C55.2, U7.A6 (SE0)
SE_ISO: C55.1, D7.1, R40.2
SE_SURGE: R40.1, R77.2
SN_ISO: C70.1, D24.1, R87.2
SN_SURGE: R83.2, R87.1
SPARE_IN: R107.2, R108.1, U1.38 (IO42)
SPI_MISO: R89.2, R90.2, R91.2, R92.2, R106.2, TP19.1, U1.17 (IO13)
SPI_MOSI: TP18.1, U1.15 (IO11), U6.F2 (I2C_DAT), U7.E7 (MOSI), U8.19 (DIN), U18.5 (DI/IO_{0}), U22.A4 (SDI)
SPI_SCK: TP17.1, U1.16 (IO12), U6.F3 (I2C_CLK), U7.F8 (SCLK), U8.20 (SCLK), U18.6 (CLK), U22.A2 (SCLK)
SP_ISO: C69.1, D23.1, R86.2
SP_SURGE: R82.2, R86.1
STATUS_LED: R88.1, U1.21 (IO17)
SWEAT_CE: D28.1, J12.13, R122.2, U7.A1 (AFE4)
SWEAT_RE: D27.1, J12.12, R121.2, U7.A2 (AFE3)
SWEAT_WE: D26.1, J12.11, R120.2, U7.C5 (AIN6)
SW_L1: L1.1, U3.9 (L1)
SW_L2: L1.2, U3.7 (L2)
TMP117_ALERT: R65.2, U1.9 (IO5), U11.3 (ALERT)
TS: J2.3, Q2.3 (D), R61.1, U2.3 (TS)
TX1: U6.D4 (TX1), U16.6 (G1_C)
TX2: U6.E5 (TX2), U16.12 (G2_C)
TX3: U6.E4 (TX3), U16.8 (R_C)
TX4: U6.C5 (TX4), U16.9 (IR_C)
TX5_EN: R25.1, U15.C1 (EN), U19.5 (P3)
TX_5V: C14.1, C89.1, R96.2, R114.1, TP5.1, U6.F5 (TX_SUP), U16.4 (IR_A), U16.5 (G1_A), U16.7 (R_A), U16.11 (G2_A), U22.A1 (VLED)
TX_5V_RAW: C47.1, R96.1, U15.B2 (VOUT), U15.C2 (FB)
TX_SW: L2.2, U15.B1 (L)
USB_CC1: J1.A5 (CC1), R1.1
USB_CC2: J1.B5 (CC2), R2.1
USB_DM: J1.A7 (D-), J1.B7 (D-), R103.1, R105.1, U21.3 (IO2), U21.4 (IO2)
USB_DM_CP: R105.2, U5.5 (D-)
USB_DM_S3: R103.2, U1.23 (IO19)
USB_DP: J1.A6 (D+), J1.B6 (D+), R102.1, R104.1, U21.1 (IO1), U21.6 (IO1)
USB_DP_CP: R104.2, U5.4 (D+)
USB_DP_S3: R102.2, U1.24 (IO20)
VBAT: C2.1, C3.1, C58.1, C82.1, C85.1, J2.1, R93.1, R107.1, TP2.1, U2.8 (OUT), U17.2 (CELL), U17.3 (VDD)
VBAT_SYS: C44.1, C46.1, L2.1, R93.2, U3.1 (EN), U3.10 (VIN), U15.A1 (VIN)
VBIAS0: C25.1, U7.C7 (VBIAS0)
VBIAS_CAP: C22.1, U7.D1 (VBIAS_CAP)
VBUS: C1.1, C10.1, C63.1, J1.A4 (VBUS), J1.A9 (VBUS), J1.B4 (VBUS), J1.B9 (VBUS), R50.1, R63.1, TP1.1, U2.1 (IN), U5.7 (VREGIN), U21.5 (VBUS)
VBUS_DET: R50.2, R51.1, U19.9 (P6)
VCAP1: C32.1, U8.11 (VCAP1)
VCAP2: C33.1, U8.27 (VCAP2)
VDD_CP2102: C9.1, C62.1, R62.1, TP6.1, U5.1 (~DCD), U5.2 (~RI/CLK), U5.6 (VDD), U5.23 (~CTS), U5.27 (~DSR)
VREF2: R18.2, U9.7 (VREF2), U9.8 (EN)
VREFP: C30.1, U8.9 (VREFP)
VREF_1V82: C20.1, U7.A5 (VREF_1V82)
VREF_2V5: C21.1, U7.D7 (VREF_2V5)
VZERO0: C24.1, U7.B7 (VZERO0)

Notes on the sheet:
J13 DNP pads: optional second ECG input pair. R118/R119 + D29/D30 fitted.
J10: LED1/2/3 cathodes, LED anode, PD cathode, PD anode.
I2C and IMU
R13 is RCAL. C27 sits between RC0_0 and RC0_1. XTAL pins are open: the internal oscillator is used.
U23 SHT45-AD1B, 0x44, skin side.
Alternate strap (DNP): move 0R to R104/R105 for the CP2102 bridge.
LED_AN ties to TX_5V through R114 (5 V headroom for green/satellite emitters).
Decoupling, RCAL, RC0
Sheets below contain the parts. They are not empty stubs.
Module decoupling
USB-C, LiPo charger, 3.3 V rail, 1.8 V rail
J12 DNP FFC: pins 1-4 = J9 order, 5-10 = J10 order, 11-13 = J11 order, 14 open.
Charge is on whenever USB is present and TS is in range. CHG_DIS high shorts TS and stops it.
Left: 1.8 V AS7341 behind PCA9306. Right: 3.3 V bus, including the IMU.
Q3 is the DevKitC auto-program pair: DTR/RTS to EN and GPIO0. R70 and R71 are the 10k bases.
Decoupling
POWER & CHARGING (root sheet)
ESP32-S3-MINI-1-N4R2. On-board PCB antenna: antenna end at the board edge over an all-layer keep-out. 4 MB flash + 2 MB PSRAM inside.
I2C sensors and IMU
Test and debug
U3 is a TPS63802 buck-boost. R23/R24 set 3.30 V. C44 and C45 are the datasheet 0603 ceramics. C3 and C4 stay.
D12 is the 730 nm LED; Q4 gate is AD5940 GPIO2 (E1). Pairs with the AS7341 NIR channel.
U4 is the 1.8 V LDO, fed from U3, EN tied to IN. AS7341 VDD is 1.7-2.0 V. Other ICs are 3.3 V.
R61 stays DNP. Fit the cell NTC, not R61 as well. R3 is 1.5k, so charge current is 200 mA.
Straps and FSR
Bias and decoupling
IO26 is the in-module PSRAM select on N4R2. IO33-37, IO47, IO48 are spare GPIO, left open.
AFE4900 PPG and second ECG lead
J7 is F+ F- S+ S-. Dedicated chest pads. Not paralleled onto J5 or J6.
J11 sweat site — RESEARCH-GRADE. WE=AIN6(C5), RE=AFE3(A2), CE=AFE4(A1); VERIFY switch matrix.
MCU
hw_v2: AIN6/AFE3/AFE4 feed J11 (RESEARCH-GRADE sweat site) and GPIO2 is NIR730_GATE. Other GPIO balls stay open.
C16 AVDD, C18 DVDD, C42 AVDD_REG, C19 IOVDD after R12, C20-C26 are the reference and bias caps.
EN has R5 10k and C64 1 uF. Q3 on the USB sheet is the DTR/RTS auto-program pair.
U5/U21/Q3 are unchanged. CP2102 keeps UART0 on ESP_TX/ESP_RX.
Fitted: J1 -> S3 IO20/IO19 (native USB, on-chip JTAG+console).
Other sheets
MAX86178 and tails
J8 Tag-Connect TC2030-NL: 1 +3V3, 2 GND, 3 ESP_TX, 4 ESP_RX, 5 EN, 6 IO0.
U25 IM69D130. PDM on IO40/IO41. 100 nF on VDD (datasheet).

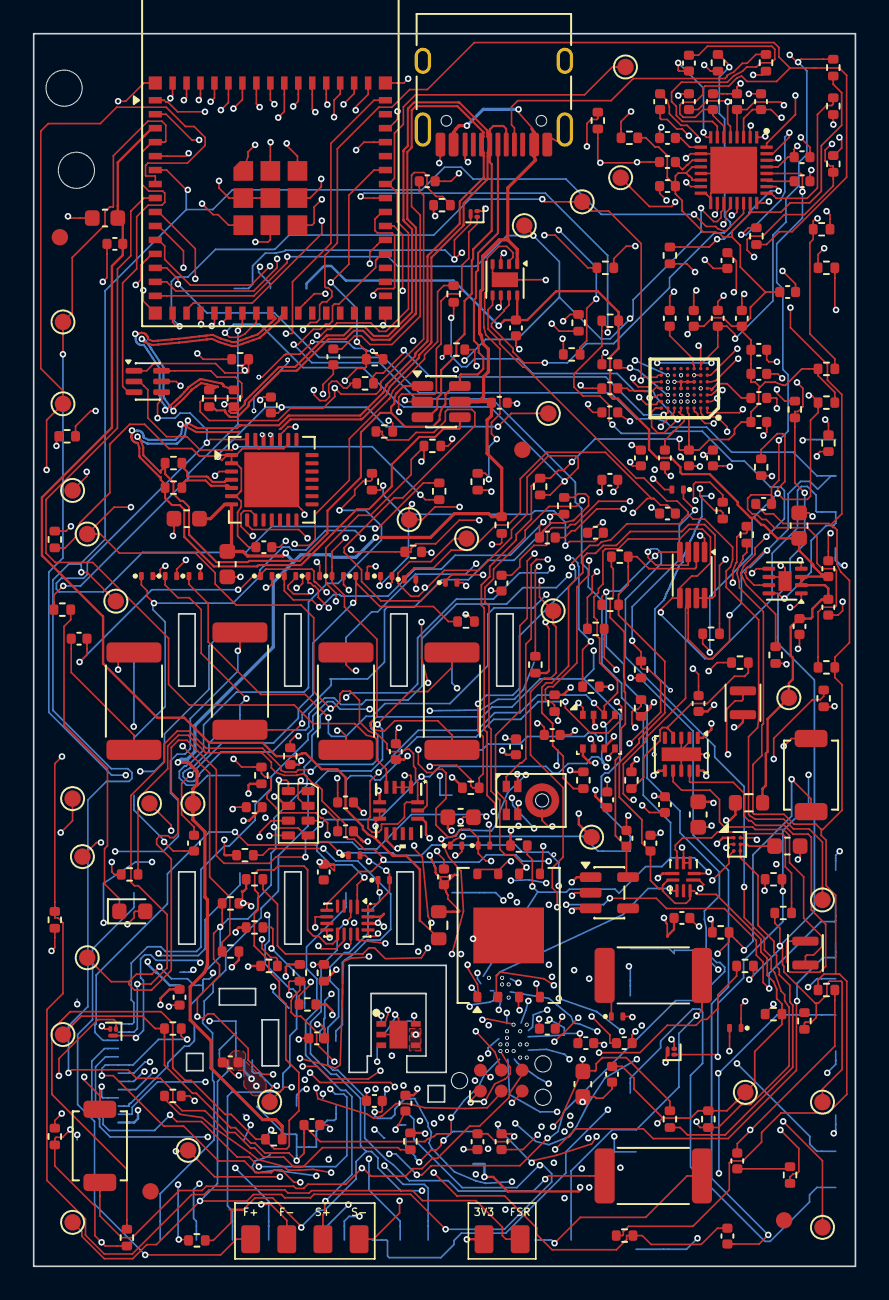
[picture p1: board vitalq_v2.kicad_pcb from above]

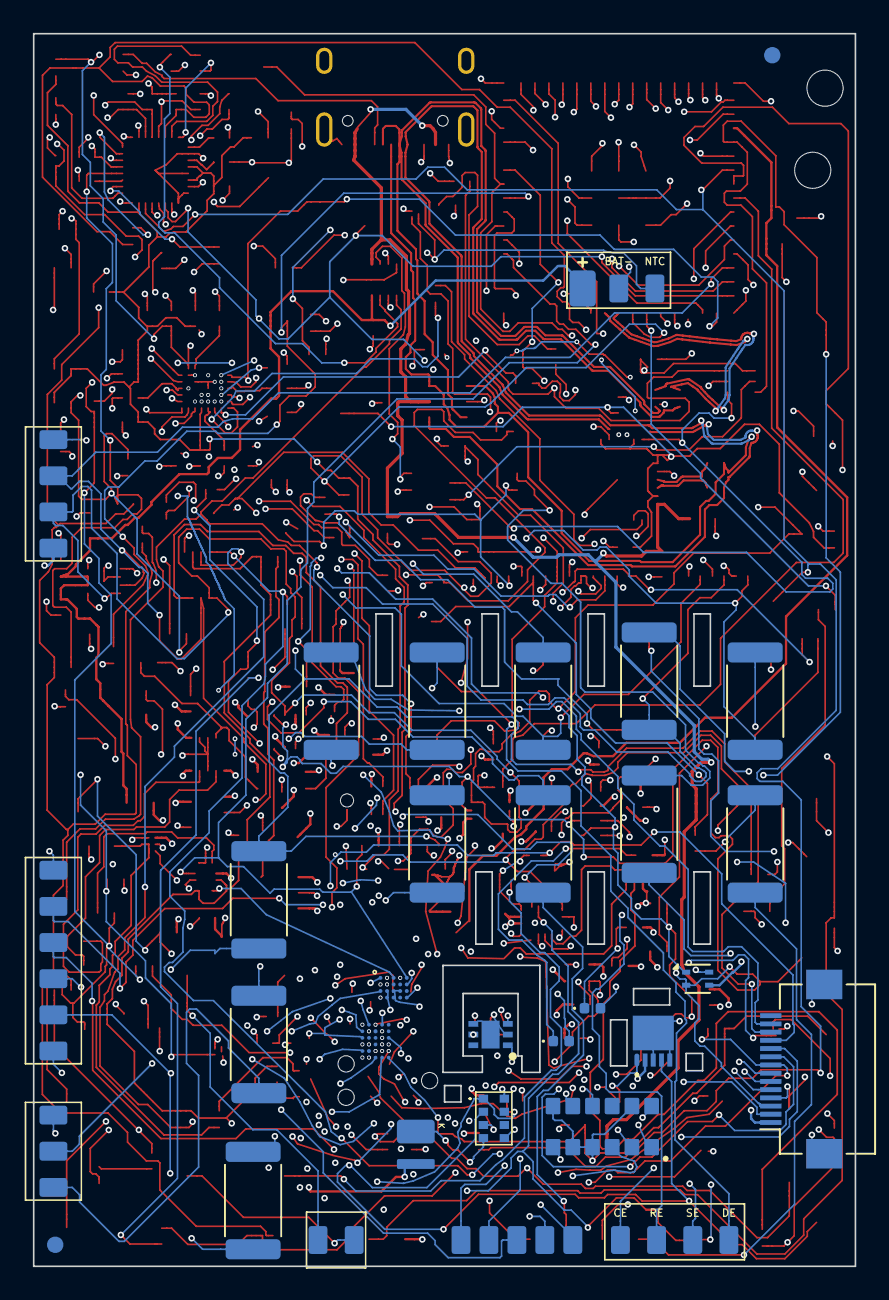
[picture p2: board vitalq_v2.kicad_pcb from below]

Board: 8 copper layers, 50.0 x 75.0 mm, 299 parts (33 on the bottom side), 191 nets.

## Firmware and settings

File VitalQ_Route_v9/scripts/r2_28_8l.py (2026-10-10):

"""R2-28 (SUPERVISOR 8-layer order): convert to 8 copper (F/In1 GND/In2/In3/In4 power/In5/In6 GND/B), keep the R2-27 placement,
blanket rip of the U6/U22/U18 region and re-route with In5 for U6 analog escapes, In3 for AFE digital/SPI, In2 for U22/U18/LED/TX.
R2-27 (SUPERVISOR placement order): U6 (+decaps C15, C79) moved +2.5 mm east away from U22, U18 nudged dx -0.31 (clears U22 C1/D1),
regional rip within 4 mm of old/new U6 and U22 (y >= 43.5, keeps the HV/U19 zone untouched), then the R2-26 lane re-route plus U22 POFVs.
R2-26 = R2-25 with the rip window kept clear of U22 (y >= 48.7; R2-25 lost 8 U22 escapes) and exact via check in the router.
R2-25 = R2-23 + reserved B-layer escape lanes for the outer-ring balls (R2-23 lost E1/F1/C5/B1 to inner-net vias/B tracks).
R2-23 (SUPERVISOR override of 3-attempt rule for the U6 wall): rip EVERYTHING within 3 mm of U6 (keep U6/U22 ball POFVs and plane stitch vias),
inner-ball fan-out on dedicated inner layers with reserved exit lanes, then outer ring, then the ripped nets. Based on R2-22 (SUPERVISOR A) with corrected order learnt from R2-21:
1) U6 outer-ring balls (B-surface escapes, most constrained) first, 2) inner corridors with STRICT layer per C-channel net
(B3 In3, D4 In2, D2 In4; no all-layer fallback), 3) easy POFV balls, 4) other U6 nets, 5) wall/other nets. Counters reset (regional rip)."""
import math
from shapely.geometry import box, LineString, Point
from r2 import STATE, save_json, state
from r2_batch import run
from r2_rip import rip, prune_orphans, reconnect
from r2_common import route_entries
import r2route
from r2route import SIGNAL_LAYERS_8 as SIGNAL_LAYERS, SMALL
import r2_u6 as U
from shapely.ops import unary_union as _uu
WIN = _uu([box(21.6, 46.8, 30.6, 55.8), box(24.1, 46.8, 33.1, 55.8), box(21.3, 43.5, 30.9, 52.2)])
PLANE_NETS = {'GND', '+3V3', 'VBAT_SYS'}


def array_guard(b, on):
    tmp = {'uuid': 'array-guard', 'name': 'array guard (inner layers)', 'parent': None, 'layers': [6, 8, 10, 12], 'tracks': True, 'vias': True, 'fills': False}
    for l in (6, 8, 10, 12):
        b.keepouts[l] = [(k, s) for k, s in b.keepouts[l] if k['uuid'] != 'array-guard']
        if on:
            b.keepouts[l].append((tmp, U.FIELD.buffer(0.15)))
    b.cache = {}

OUTER_FIRST = ['C1', 'F3', 'E1', 'F1', 'F4', 'F5', 'C5', 'B1', 'A4', 'B5', 'A5', 'D1']
INNER = ['B3', 'D4', 'D2', 'C4', 'E3', 'E4', 'E2', 'B2']
GNDB = ['B4', 'D1', 'D5']
U22B = ['C1', 'D1', 'A2', 'A4', 'B1', 'B2']
EASY = ['A1', 'A2', 'A3', 'E5', 'F2']
# supervisor grouping (In1 is the GND plane, so 'power' nets go to In4 = Power Layer 5); C-channel needs 3 distinct layers -> AFE_BG on In2
# 8L: In5 analog (PD2_INM/PD2_INP), In3 AFE digital (CS/MISO + AFE_BG: the C-channel needs 3 distinct layers), In2 TX/power
STRICT = {'B3': (12, 2, 0), 'B2': (12, 2, 0), 'D2': (8, 2, 0), 'E3': (8, 2, 0), 'E2': (8, 2, 0), 'D4': (6, 2, 0), 'E4': (6, 2, 0), 'C4': (6, 2, 0)}
LANE_LAYER = {'B3': 12, 'B2': 12, 'D2': 8, 'E3': 8, 'E2': 8, 'D4': 6, 'E4': 6, 'C4': 6}
PREF = {}
for _n in ('PD2_INP', 'PD2_INM', 'AFE_BG', 'AFE_INP', 'AFE_INM', 'PD_INP', 'PD_INM'):
    PREF[_n] = 12
for _n in ('CS_AFE4900', 'MISO_AFE', 'SPI_SCK', 'SPI_MOSI', 'AFE_CLK', 'AFE4900_RESETZ', 'AFE4900_ADC_RDY'):
    PREF[_n] = 8
for _n in ('CS_FLASH', 'MISO_FL', 'MX_SDO_1V8', 'LED1_K', 'LED2_K', 'LED3_K', 'TX1', 'TX2', 'TX3', 'TX4', 'TX_5V'):
    PREF[_n] = 6
BASE_COST = dict(r2route.LAYER_COST)
_orig_route = r2route.route


def _route_pref(b, net, *a, **k):
    r2route.LAYER_COST.clear()
    r2route.LAYER_COST.update(BASE_COST)
    if net in PREF:
        for l in (6, 8, 12):
            r2route.LAYER_COST[l] = 1.25
        r2route.LAYER_COST[PREF[net]] = 0.85
    return _orig_route(b, net, *a, **k)


import r2_common
r2_common.route = _route_pref
APP = 'R2-28 8-layer, U6 +2.5 east, region rip; dedicated inner layer per inner ball with reserved exit lanes; corridors first, outer ring, then ripped nets; 60 s budget'
REGION = [21.3, 43.5, 33.1, 55.8]
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

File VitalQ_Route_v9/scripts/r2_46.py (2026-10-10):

"""R2-46 (user priority: last opens first): U6 E2 MISO_AFE, F1 AFE_CLK, B3 PD2_INM. POFV 0.25/0.15 at the ball centre, escape on In3/In5 or
In4 (power layer, local; pocket analysis shows In3/In5 walled, In4 open), via up near the destination. The SPI_MOSI segment on the F1 POFV
site is ripped and SPI_MOSI re-routed on another layer in the same batch. Longer per-route budget (180 s); In4 cost lowered for these nets."""
import math
import r2route
from r2_batch import run
from r2_common import route_entries, open_comps
from r2_rip import rip, reconnect
from r2route import SMALL

SL = (0, 2, 6, 8, 12, 10)
APP = 'R2-46 POFV ball escape on In3/In5/In4 (local), 180 s budget'
BALLS = {'E2': 'MISO_AFE', 'F1': 'AFE_CLK', 'B3': 'PD2_INM'}
_orig = r2route.route


def _route(*a, **k):
    k['time_budget'] = 180.0
    k['max_expand'] = 4_000_000
    return _orig(*a, **k)


import r2_common
r2_common.route = _route
r2route.LAYER_COST[10] = 1.2


def plan(b, ledger, opens):
    j8 = [k['uuid'] for k in b.raw['keepouts'] if k['parent'] == 'J8']
    u6 = {p['number']: p for p in b.raw['pads'] if p['ref'] == 'U6'}
    blockers = set()
    for num in BALLS:
        p = u6[num]
        for h in b.via_issues_exact(p['net'], p['xy'], *SMALL, ignore_keepouts=j8):
            if h['kind'] == 'tracks':
                blockers.add(h['uuid'])
    ripped = {b.items[u]['net'] for u in blockers}
    rip(b, ledger, list(blockers), 'R2-46: blocks a U6 POFV site')
    print('ripped', ripped, flush=True)
    vias = {}
    for num in BALLS:
        p = u6[num]
        if b.via_issues_exact(p['net'], p['xy'], *SMALL, ignore_keepouts=j8):
            print('site still blocked', num, flush=True)
            continue
        v = {'net': p['net'], 'xy': list(p['xy']), 'diameter': SMALL[0], 'drill': SMALL[1], 'pofv': True, 'pad': 'U6.' + num}
        b.add_items([], [v])
        vias[num] = v
    for it in opens:
        t = ' '.join(e['description'] for e in it['items'])
        num = next((n for n, net in BALLS.items() if f'Pad {n} [{net}] of U6' in t), None)
        if num is None or num not in vias:
            continue
        info = open_comps(b, it)
        net, comps, (ka, kb) = info
        a, c = comps[ka], comps[kb]
        src, dst = (a, c) if any(e['kind'] == 'pads' and e.get('ref') == 'U6' for e, _ in a) else (c, a)
        r = route_entries(b, net, src, dst, net + ' R2-46', [(APP + ', margin 8 mm', 8.0, SL), (APP + ', margin 20 mm', 20.0, SL)], ledger['routes'], small_vias=False)
        print('OPEN', num, net, 'ok' if r else 'FAILED', flush=True)
        if not r:
            rip(b, ledger, [vias[num]['uuid']], 'rollback U6.' + num + ' POFV')
    if ripped:
        reconnect(b, ledger, ripped, [24.0, 47.0, 32.0, 56.0], [(APP + ' (ripped blocker, other layer), margin 5 mm', 5.0, SL), (APP + ' (ripped blocker), margin 12 mm', 12.0, SL)])


run('R2-46', 'U6_last_balls', plan, j8={'original_outline': [{'outer': [[27.72, 50.065], [25.18, 50.065], [25.18, 51.335], [27.72, 51.335]], 'holes': []}]}, adopt_if_fewer_opens=True, next_step='PD_A, C59, I2C_SDA')

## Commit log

2026-10-10 VitalQ_Route_v9 trials batch 1
    [vitalq_v2.kicad_pcb, vitalq_v2.kicad_sch]
2026-10-10 VitalQ_Route_v9 trials batch 2
    [vitalq_v2.kicad_pcb, vitalq_v2.kicad_sch]
2026-10-10 VitalQ_Route_v9 trials batch 3
    [vitalq_v2.kicad_pcb, vitalq_v2.kicad_sch]
2026-10-10 VitalQ_Route_v9 trials batch 4
    [vitalq_v2.kicad_pcb, vitalq_v2.kicad_sch]
2026-10-10 VitalQ_Route_v9 trials batch 5
    [vitalq_v2.kicad_pcb, vitalq_v2.kicad_sch]
2026-10-10 VitalQ_Route_v9 trials batch 6
    [vitalq_v2.kicad_pcb, vitalq_v2.kicad_sch]
2026-10-10 VitalQ_Route_v9 trials batch 7
    [vitalq_v2.kicad_pcb, vitalq_v2.kicad_sch]
2026-10-10 VitalQ_Route_v9 trials batch 8
    [vitalq_v2.kicad_pcb, vitalq_v2.kicad_sch]
2026-10-10 VitalQ_Route_v9 trials batch 9
    [vitalq_v2.kicad_pcb, vitalq_v2.kicad_sch]
2026-10-10 VitalQ_Route_v9 trials batch 10
    [vitalq_v2.kicad_pcb, vitalq_v2.kicad_sch]
2026-10-10 VitalQ_Route_v9 trials batch 11
    [vitalq_v2.kicad_pcb, vitalq_v2.kicad_sch]
2026-10-10 VitalQ_Route_v9 trials batch 12
    [vitalq_v2.kicad_pcb, vitalq_v2.kicad_sch]
2026-10-10 VitalQ_Route_v9 trials batch 13
    [vitalq_v2.kicad_pcb, vitalq_v2.kicad_sch]
2026-10-10 VitalQ_Route_v9 trials batch 14
    [vitalq_v2.kicad_pcb, vitalq_v2.kicad_sch]
2026-10-10 VitalQ_Route_v9 trials batch 15
    [vitalq_v2.kicad_pcb, vitalq_v2.kicad_sch]
2026-10-10 VitalQ_Route_v9 trials batch 16
    [vitalq_v2.kicad_pcb, vitalq_v2.kicad_sch]
2026-10-10 VitalQ_Route_v9 trials batch 17
    [vitalq_v2.kicad_pcb, vitalq_v2.kicad_sch]
2026-10-10 VitalQ_Route_v9 trials batch 18
    [vitalq_v2.kicad_pcb, vitalq_v2.kicad_sch]
2026-10-10 VitalQ_Route_v9 trials batch 19
    [vitalq_v2.kicad_pcb, vitalq_v2.kicad_sch]
2026-10-10 VitalQ_Route_v9 trials batch 20
    [vitalq_v2.kicad_pcb, vitalq_v2.kicad_sch]
2026-10-10 VitalQ_Route_v9 trials batch 21
    [vitalq_v2.kicad_pcb, vitalq_v2.kicad_sch]
2026-10-10 VitalQ_Route_v9 trials batch 22
    [vitalq_v2.kicad_pcb, vitalq_v2.kicad_sch]
2026-10-10 VitalQ_Route_v9 trials batch 23
    [vitalq_v2.kicad_pcb, vitalq_v2.kicad_sch]
2026-10-10 VitalQ_Route_v9 trials batch 24
    [vitalq_v2.kicad_pcb, vitalq_v2.kicad_sch]
2026-10-10 VitalQ_Route_v9 trials batch 25
    [vitalq_v2.kicad_pcb, vitalq_v2.kicad_sch]
2026-10-10 VitalQ_Route_v9 trials batch 26
    [vitalq_v2.kicad_pcb, vitalq_v2.kicad_sch]
2026-10-10 VitalQ_Route_v9 trials batch 27
    [vitalq_v2.kicad_pcb, vitalq_v2.kicad_sch]
2026-10-10 VitalQ_Route_v9 trials batch 28
    [vitalq_v2.kicad_pcb, vitalq_v2.kicad_sch]
2026-10-10 VitalQ_Route_v9 trials batch 29
    [vitalq_v2.kicad_pcb, vitalq_v2.kicad_sch]
2026-10-10 VitalQ_Route_v9 trials batch 30
    [vitalq_v2.kicad_pcb, vitalq_v2.kicad_sch]
2026-10-10 VitalQ_Route_v9 trials batch 31
    [vitalq_v2.kicad_pcb, vitalq_v2.kicad_sch]
2026-10-10 VitalQ_Route_v9 trials batch 32
    [vitalq_v2.kicad_pcb, vitalq_v2.kicad_sch]
2026-10-10 VitalQ_Route_v9 trials batch 33
    [vitalq_v2.kicad_pcb, vitalq_v2.kicad_sch]
2026-10-10 VitalQ_Route_v9 trials batch 34
    [vitalq_v2.kicad_pcb, vitalq_v2.kicad_sch]
2026-10-10 VitalQ_Route_v9 trials batch 35
    [vitalq_v2.kicad_pcb, vitalq_v2.kicad_sch]
2026-10-10 VitalQ_Route_v9 trials batch 36
    [vitalq_v2.kicad_pcb, vitalq_v2.kicad_sch]
2026-10-10 VitalQ_Route_v9 trials batch 37
    [vitalq_v2.kicad_pcb, vitalq_v2.kicad_sch]
2026-10-10 VitalQ_Route_v9 trials batch 38
    [vitalq_v2.kicad_pcb, vitalq_v2.kicad_sch]
2026-10-10 VitalQ_Route_v9 trials batch 39
    [vitalq_v2.kicad_pcb, vitalq_v2.kicad_sch]
